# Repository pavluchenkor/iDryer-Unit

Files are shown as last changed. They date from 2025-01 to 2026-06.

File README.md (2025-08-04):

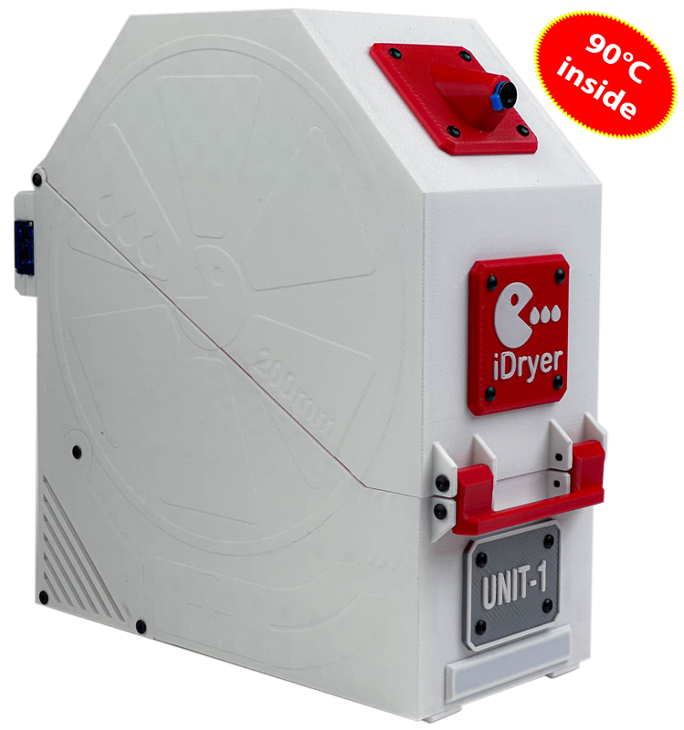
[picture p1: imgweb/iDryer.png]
iDryer Unit Master



    

# iDryer Unit - Filament Drying System for 3D Printers Based on Klipper

### Project Release

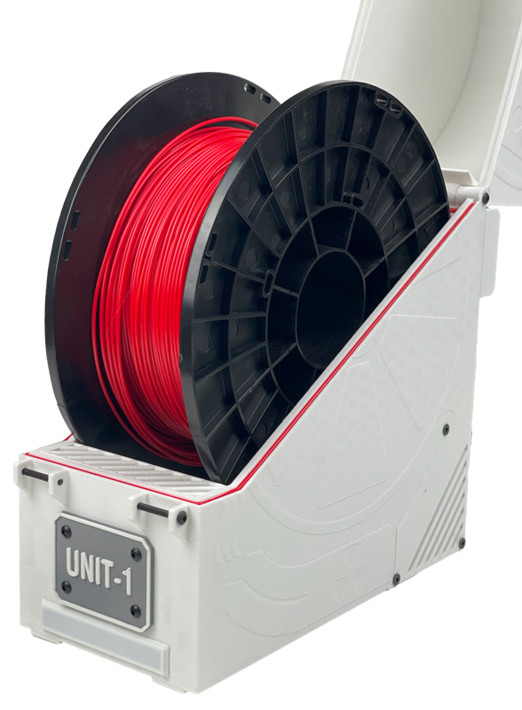
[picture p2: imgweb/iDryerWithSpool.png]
iDryer Unit Master


This project is a modular filament drying control system for 3D printers. It supports up to four drying units, each with individual temperature and humidity settings. The system allows setting temperatures up to 90°C and includes a storage mode that maintains minimal humidity to prevent filament reabsorption.

Additionally, iDryer Unit supports connection to a Telegram bot to receive notifications about drying status, process completion, and events like overheating. For visual indication, addressable LEDs can be used-an output on the MCU board allows connecting an LED strip to display various states (e.g., active drying mode, cycle completion, or errors). The system can leverage Klipper functionality to show temperature, humidity, remaining drying time, automatically log events, and integrate with macros. It also supports advanced user profiles and extended scenarios such as scheduled startup, critical event alerts, and lighting features like color changes between modes.

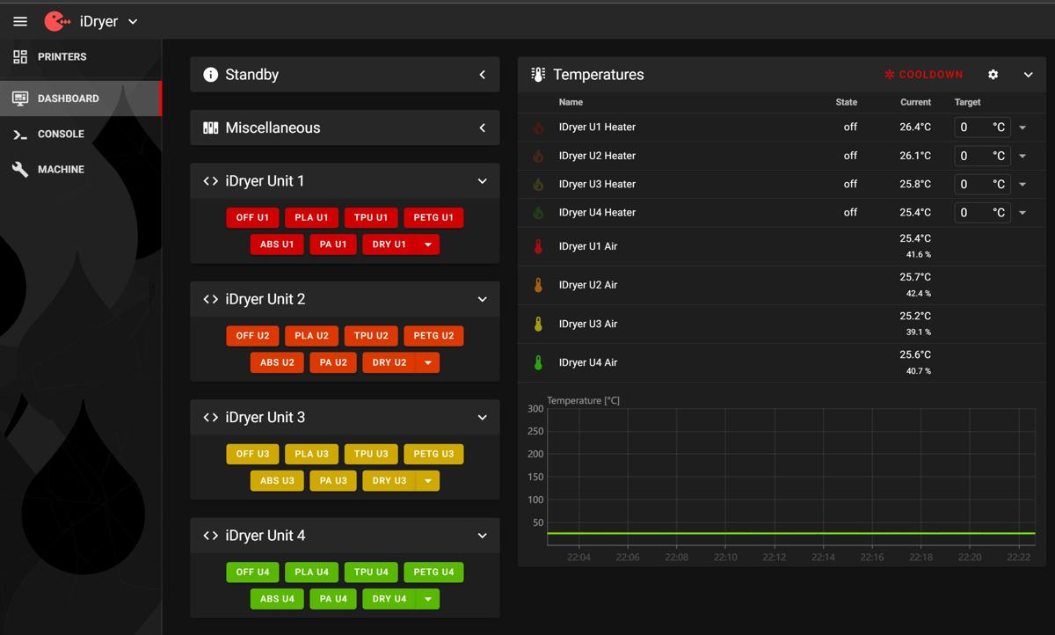
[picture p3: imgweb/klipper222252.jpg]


## Key Features

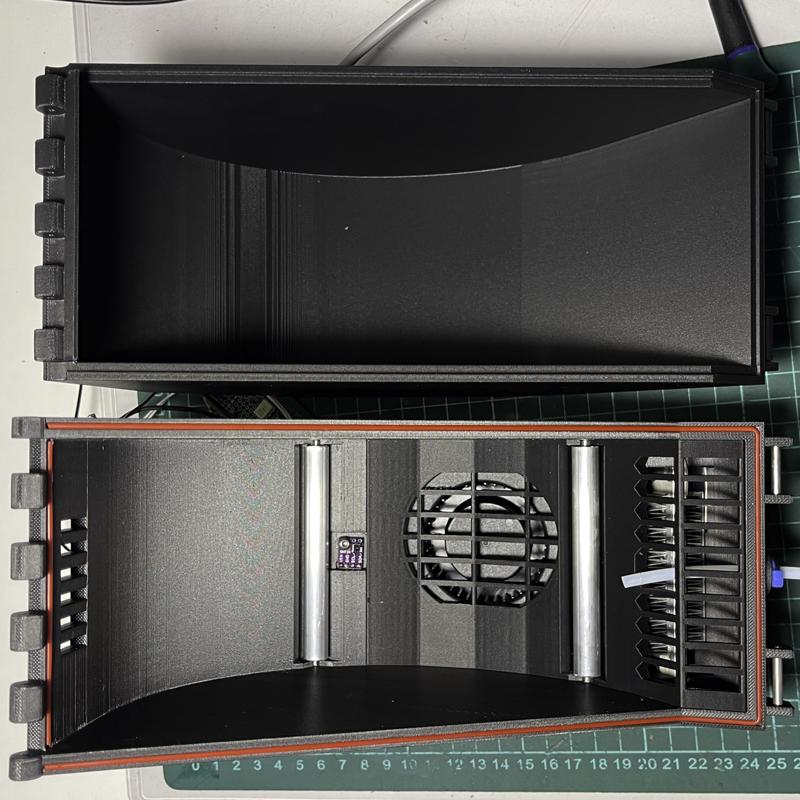
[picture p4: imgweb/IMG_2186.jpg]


* **Operating Modes: Drying and Storage.** Drying filament up to 90°C and maintaining ideal temperature and humidity for storage.

* **Modular Design:**

  * **iDryer Unit MCU** - main control unit with microcontroller.

  * **iDryer Unit EXT** - expansion modules without microcontrollers, connectable to the MCU unit. Up to three EXT units can be added.

* **Klipper Integration:** Display all drying parameters within Klipper interface.

* **Telegram Bot Notifications:** Receive real-time updates about status and process completion.

* **Visual Indication:** Addressable LEDs display current operating modes.

* **Printable Enclosure:** Available for one or two spools. Compatible with spools up to 85 mm wide and 200 mm in diameter. Can be printed using ABS or other suitable filament.

* **System Scalability:** Supports up to four drying units with individual settings. Each dryer can handle one or two spools simultaneously.

* **Add-on Module Support:** Additional dryers connect via patch cords using RJ45 connectors for reliable communication.

* **Centralized Architecture:** One dryer unit has an MCU and acts as the controller, while others are peripherals. iDryer can also be set up as a standalone Klipper instance or as a secondary MCU connected to the main printer board.

* **Safety:** Includes 130°C KSD9700 thermostat and Klipper safety mechanisms.

* **Drying Efficiency:** Features a humidity sensor and a servo-driven damper to manage chamber ventilation and achieve optimal drying results.
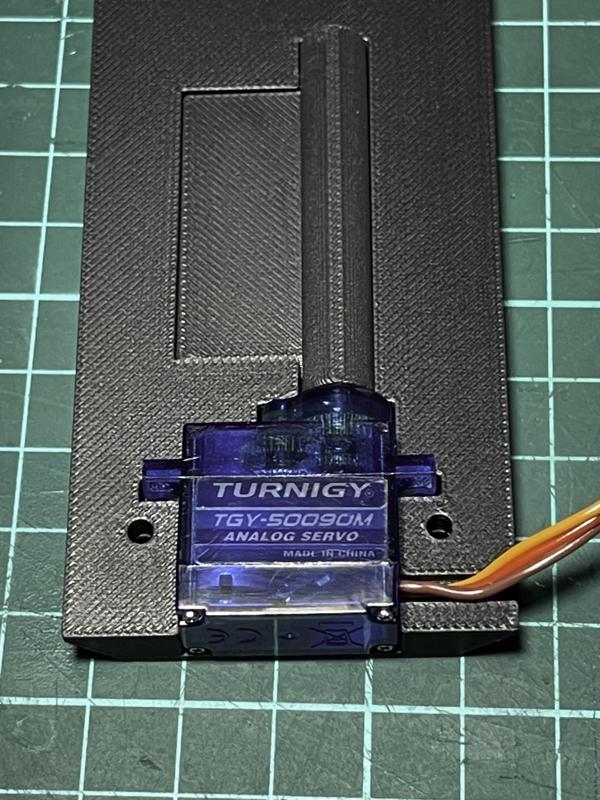
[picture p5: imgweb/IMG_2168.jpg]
  
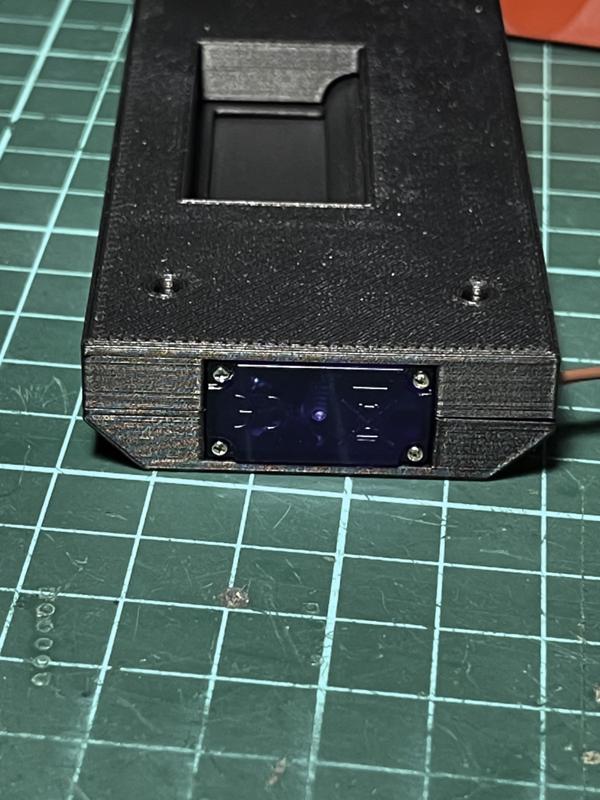
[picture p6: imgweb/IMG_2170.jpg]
  

## Benefits of Use

* **Improved Print Quality:** Dry filament ensures consistent extrusion and better print results.
* **Time Savings:** Simultaneous drying of multiple spools.
* **Efficiency:** Boosts productivity by reducing drying time.
* **Flexibility:** Expandable and customizable for specific needs.
* **Visualization:** LED feedback enables quick device status assessment.
* **Safety:** Both hardware and firmware safety measures ensure secure operation.

## Technical Details

* **iDryer Unit MCU:** Main controller block with microcontroller.
* **iDryer Unit EXT:** Expansion module without microcontroller.
* **MCU:** Manages the main dryer and coordinates additional modules. Default connection is U1; U2-U4 are optional. iDryer can function as a separate Klipper instance or as a second MCU within a single Klipper setup.
* **Thermostat KSD9700:** 130°C bimetallic thermostat for emergency protection.
* **Temperature Range:** Drying up to 90°C, suitable for most filament types.
* **Connection Interfaces:** RJ45 connectors simplify installation and ensure reliable connections.
* **LED Output:** Allows connecting addressable LED strips for visual feedback.

## Operating Modes

**1. Drying Mode (DRYING)**

* Set temperature and drying duration.
* Automatically switches to storage mode upon completion.

**2. Storage Mode (STORAGE)**

* Maintains target temperature and humidity.
* Activates heater and fan if thresholds are exceeded.

## Setup and Configuration

**Connection:** Link additional modules to the main dryer using RJ45 patch cords. U1 connects by default; U2-U4 can be added by including the appropriate config files.

## Requirements

* 3D printer with up-to-date Klipper firmware.
* iDryer board with MCU for the main dryer.
* KSD9700 thermostat (130°C) per dryer.
* RJ45 patch cords and connectors to link expansion modules.
* Extra iDryer Unit control boards depending on the number of dryers used.

---

## Feedback

If you have questions or suggestions for improvement, please open an issue in the repository or reach out directly.

Or join the Telegram group.

## Notes

* Ensure temperature and humidity sensors (e.g., SHT3X or alternatives) are connected correctly.
* PID tuning may be needed for optimal temperature control.
* Use macros to monitor temperature and humidity readings for precise drying conditions.
* This project is under active development.

***Warning: Using heating elements and temperature control involves fire risk and potential equipment damage. Always follow manufacturer guidelines and adhere to electrical safety precautions. Never leave operating devices unattended.***

### DIY Version from Scrap Materials

You can build a prototype of the iDryer Unit yourself on a minimal budget. This is a prototype and should be treated accordingly.

[EasyEDA Project](https://oshwlab.com/pavluchenko.r/2channel-dimmer-bread-board)

### Using a Printer Board

Another excellent option is to reuse an old printer board as an MCU, with solid-state relays to control 110-220V loads.






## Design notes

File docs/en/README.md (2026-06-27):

# iDryer Unit

iDryer Unit is a modular filament drying and storage system for 3D printers. Printable enclosure for 1 or 2 spools, up to four independent drying chambers in a single system.

Drying temperature — up to 90 °C in a standard enclosure, up to 110 °C with heat-resistant enclosure materials. Supported modes: Drying, Storage, and Profile.

iDryer Unit

## Who this project is for

iDryer Unit is a DIY project for those who want a reliable dryer with real control over the process, not a ready-made commercial device with a closed-source interior.

All components are standard and readily available: fan, PTC heater, temperature and humidity sensor, servo, Thermal Protector. Any of them can be replaced without searching for proprietary spare parts. Unlike most mass-produced dryers, there is nothing here that cannot be repaired or improved.

The enclosure is printed on any 3D printer. Schematics, firmware, and documentation are open.

iDryer Unit with spool

---

## Two modes of operation

Choose a scenario before starting assembly — it determines the firmware and control method.

### Klipper

Klipper

The Unit controller connects to the printer host and operates as `[mcu]` or `[second_mcu]` in Klipper. Control is via the Fluidd / Mainsail interface, G-code macros, and integration with the main printer config.

Additional Klipper features are available: notifications via Telegram bot (drying status, cycle completion, overheating), addressable LED strip for visual mode indication, automatic event logging.

Suitable if:

- you already have Klipper running;
- you want to control the dryer directly from the printer interface;
- you need deep integration with macros and scheduling.

→ [Klipper Firmware](controller/firmware.md)

### Standalone

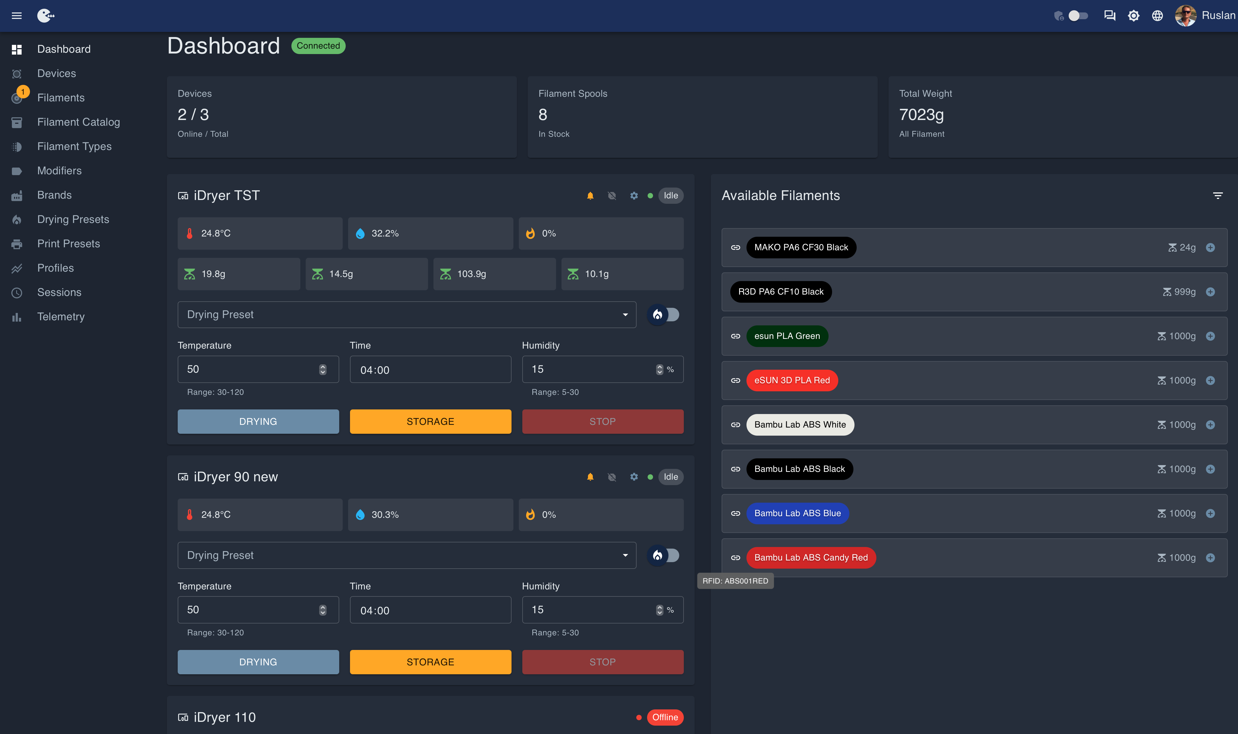
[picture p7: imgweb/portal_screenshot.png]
iDryer Portal


The controller operates independently: its own firmware, control via the cloud portal [portal.idryer.org](https://portal.idryer.org/) and mobile app. Optionally — local control via OLED display and encoder. Scales (filament remainder control by weight) and RFID (automatic spool identification) are supported.

Suitable if:

- you want a dryer separate from the printer;
- you need remote control via mobile app or portal;
- you use multiple dryers with a single control point.

→ [Standalone: about firmware](../../../iDryerRP2040/README.md)

---

## Specifications

| Parameter | Value |
|---|---|
| Drying temperature | up to 90 °C (up to 110 °C with heat-resistant enclosure) |
| Modes | Drying, Storage, Profile (Standalone) |
| Number of chambers | 1–4 (MCU + up to 3 × EXT) |
| Module connection | RJ45 patch cables |
| Thermal Protector | KSD9700 (130 °C) |
| Current protection | 2 A fuse |
| Heating element | PTC, full electrical isolation |
| Spools | 1 or 2 per chamber; width up to 85 mm, diameter up to 200 mm |
| Enclosure options | Single-spool and dual-spool |
| Enclosure material | Printable, ABS / ABS-CF / PC / HTPLA |
| Humidity sensor | SHT3X or any supported by firmware |
| LED indication | Addressable LED strip output on MCU board |

---

## Operating modes

**Drying** — set temperature and duration. When the cycle ends, the system automatically switches to Storage mode.

**Storage** — maintains the set temperature and minimum humidity level. The heater and fan activate when the set parameters are exceeded.

**Profile** — custom scenarios with configurable parameters and transitions between modes. Available in Standalone firmware.

---

## Humidity control

Each chamber has a servo-controlled damper. The servo opens the damper on a schedule to vent moisture-saturated air and closes it to retain heat. The SHT3X sensor continuously monitors temperature and humidity inside the chamber — the firmware adjusts the damper and heater operation based on this data.

iDryer Unit damper
Damper mechanism

---

## System architecture

One **iDryer Unit MCU** board controls the system. Up to three **iDryer Unit EXT** boards (without their own microcontroller) connect directly via RJ45.

```
              ┌— RJ45 — [EXT U2]
[MCU] ————————┼— RJ45 — [EXT U3]
              └— RJ45 — [EXT U4]
```

Each unit is an independent drying chamber with its own sensor, heater, fan, and damper servo.

---

## Built-in safety

- **KSD9700** — Thermal Protector at 130 °C: physically opens the heater circuit on overheating.
- **2 A fuse** — protection against fault currents.
- **PTC heater** — the heater body is not live.
- **Software protection** — Klipper (or Standalone firmware) monitors temperature, sensor presence, and shuts off heating on error.

!!! danger "Working with mains voltage"
    The device contains components operating at 110–230 V. Disconnect power before any electrical work. See the [Safety](unit/safety.md) section for details.

---

## Getting started

1. **Print the enclosure** → [CAD: models for printing](unit/cad.md)
2. **Prepare components** → [Before assembly](unit/before.md)
3. **Assemble the device** → [Assembly](unit/assembly.md)
4. **Install firmware**:
   - Klipper → [Klipper Firmware](controller/firmware.md)
   - Standalone → [Standalone installation](../../../iDryerRP2040/docs/manual/firmware_install.md)
5. **Configure the system** → [User guide](controller/user-guide.md)

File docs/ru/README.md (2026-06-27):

# iDryer Unit

iDryer Unit — модульная система сушки и хранения филамента для 3D-принтеров. Печатаемый корпус на 1 или 2 катушки, до четырёх независимых сушильных камер в одной системе.

Температура сушки — до 90 °C в стандартном корпусе, до 110 °C при использовании теплостойких материалов корпуса. Поддерживаемые режимы — сушка (Drying), хранение (Storage) и профили (Profile).

iDryer Unit

## Для кого этот проект

iDryer Unit — DIY-проект для тех, кто хочет надёжную сушилку с реальным контролем над процессом, а не готовое коммерческое устройство с закрытой начинкой.

Все компоненты — стандартные и доступные: вентилятор, PTC-нагреватель, датчик температуры и влажности, сервопривод, Thermal Protector. Любой из них можно заменить без поиска фирменных запчастей. В отличие от большинства серийных сушилок, здесь нет ничего, что нельзя починить или улучшить.

Корпус печатается на любом 3D-принтере. Схемы, прошивки и документация открыты.

iDryer Unit с катушкой

---

## Два варианта работы

Выберите сценарий до начала сборки — от него зависит прошивка и способ управления.

### Klipper

Klipper

Контроллер Unit подключается к хосту принтера и работает как `[mcu]` или `[second_mcu]` в Klipper. Управление — через интерфейс Fluidd / Mainsail, макросы G-кода, интеграция с основным конфигом принтера.

Доступны дополнительные функции Klipper: уведомления через Telegram-бот (статус сушки, завершение цикла, перегрев), адресная светодиодная лента для визуальной индикации режимов, автологирование событий.

Подходит, если:

- у вас уже работает Klipper;
- хотите управлять сушилкой прямо из интерфейса принтера;
- нужна глубокая интеграция с макросами и расписанием.

→ [Прошивка Klipper](controller/firmware.md)

### Standalone

iDryer Portal

Контроллер работает самостоятельно: своя прошивка, управление через облачный портал [portal.idryer.org](https://portal.idryer.org/) и мобильное приложение. Опционально — локальное управление через OLED-экран и энкодер. Поддерживаются весы (контроль остатка филамента по весу) и RFID (автоматическое определение катушки).

Подходит, если:

- хотите сушилку отдельно от принтера;
- нужен удалённый контроль через мобильное приложение или портал;
- используете несколько сушилок с одной точкой управления.

→ [Standalone: о прошивке](../../../iDryerRP2040/README.md)

---

## Характеристики

| Параметр | Значение |
|---|---|
| Температура сушки | до 90 °C (до 110 °C с теплостойким корпусом) |
| Режимы | Drying, Storage, Profile (Standalone) |
| Количество камер | 1–4 (MCU + до 3 × EXT) |
| Подключение модулей | RJ45 патчкорды |
| Thermal Protector | KSD9700 (130 °C) |
| Защита по току | предохранитель 2 А |
| Нагревательный элемент | PTC, полная электрическая изоляция |
| Катушки | 1 или 2 на камеру; ширина до 85 мм, диаметр до 200 мм |
| Варианты корпуса | На 1 катушку и на 2 катушки |
| Материал корпуса | Печатаемый, ABS / ABS-CF / PC / HTPLA |
| Датчик влажности | SHT3X или любой, поддерживаемый прошивкой |
| Светодиодная индикация | выход для адресной LED-ленты на плате MCU |

---

## Режимы работы

**Drying (сушка)** — задайте температуру и время. По истечении цикла система автоматически переходит в режим Storage.

**Storage (хранение)** — поддерживает заданную температуру и минимальный уровень влажности. Нагреватель и вентилятор включаются при превышении заданных параметров.

**Profile (профиль)** — пользовательские сценарии с настраиваемыми параметрами и переходами между режимами. Доступен в Standalone-прошивке.

---

## Управление влажностью

Каждая камера оснащена управляемой заслонкой. Сервопривод открывает заслонку по расписанию для вывода насыщенного влагой воздуха и закрывает её для удержания тепла. Датчик SHT3X непрерывно контролирует температуру и влажность внутри камеры — прошивка корректирует режим работы заслонки и нагревателя на основе этих данных.

Заслонка iDryer Unit
Механизм заслонки

---

## Архитектура системы

Один блок **iDryer Unit MCU** управляет системой. К нему напрямую через RJ45 подключаются до трёх блоков **iDryer Unit EXT** без собственного микроконтроллера.

```
              ┌— RJ45 — [EXT U2]
[MCU] ————————┼— RJ45 — [EXT U3]
              └— RJ45 — [EXT U4]
```

Каждый блок — независимая сушильная камера со своими датчиком, нагревателем, вентилятором и сервоприводом заслонки.

---

## Встроенная безопасность

- **KSD9700** — Thermal Protector на 130 °C: физически размыкает цепь нагревателя при перегреве.
- **Предохранитель 2 А** — защита при аварийных токах.
- **PTC-нагреватель** — корпус нагревателя не находится под напряжением.
- **Программная защита** — Klipper (или Standalone-прошивка) контролирует температуру, наличие датчиков и отключает нагрев при ошибке.

!!! danger "Работа с сетевым напряжением"
    Устройство содержит компоненты под напряжением 110–230 В. Перед любыми работами с электрикой отключайте питание. Подробнее — в разделе [Безопасность](unit/safety.md).

---

## С чего начать

1. **Распечатайте корпус** → [CAD: модели для печати](unit/cad.md)
2. **Подготовьте комплектующие** → [Перед сборкой](unit/before.md)
3. **Соберите устройство** → [Сборка](unit/assembly.md)
4. **Установите прошивку**:
   - Klipper → [Прошивка Klipper](controller/firmware.md)
   - Standalone → [Установка Standalone](../../../iDryerRP2040/docs/manual/firmware_install.md)
5. **Настройте систему** → [Руководство пользователя](controller/user-guide.md)

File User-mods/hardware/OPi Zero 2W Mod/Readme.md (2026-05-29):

# [OPi_Zero_2W_Mod]

>[!NOTE]
>На момент разработки модификации возможность автономной работы iDryer Unit отсутствовала - модификация **может быть актуальна** для плат старше 2025 года.

Модификация для сушилки iDryer, позволяющая использовать её независимо от принтера за счёт увеличенного отсека электроники и установки OPi Zero 2w. Для максимальной компактности в части кабель-менеджемента крайне рекомендуется делать совместно с [UART mod](https://github.com/DieselFork/iDryer-Unit/tree/main/User-mods/hardware/UART%20mod).

>[!WARNING]
>Работоспособность UART мода обеспечивается использованием одного из разъёмов расширения - одновременно можно будет подключить только 2 EXT платы.

## Рендеры

### Вид спереди

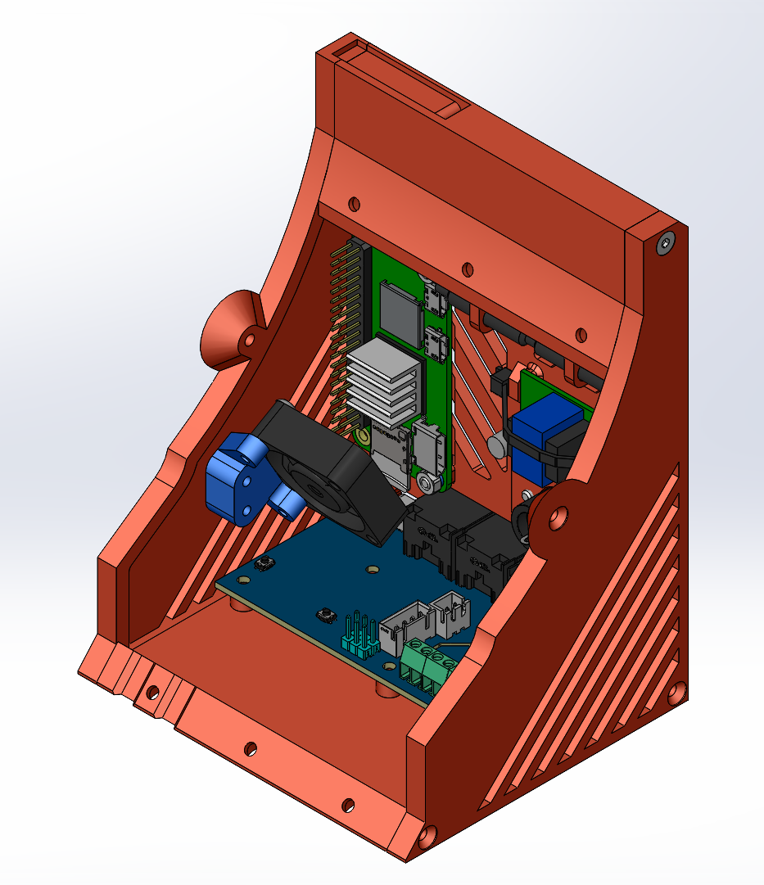
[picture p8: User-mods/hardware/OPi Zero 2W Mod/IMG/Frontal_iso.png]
Фронтальная_изометрическая_проекция


### Вид сзади

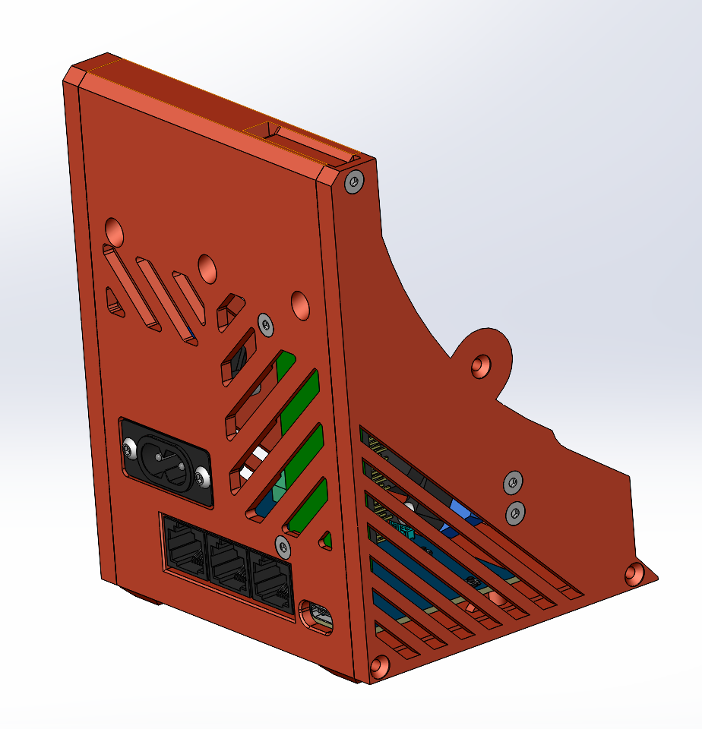
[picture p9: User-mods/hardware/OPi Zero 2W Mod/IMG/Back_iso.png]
Вид_сзади


## BOM

### Докупаемые детали

1. [Orange Pi Zero 2 W](https://aliexpress.ru/item/1005007543231333.html), желательно брать версию с 2 Гб памяти, с расчётом на дополнительные модификации.
2. [Блок питания 5В, 2А](https://aliexpress.ru/item/1005001970797548.html?sku_id=12000018270798953), не менее. Если сделать не очень качественно серво-заслонку (когда шторка цепляется за корпус), то могут быть просадки по питанию.
3. [Вентилятор 3010, 5В](https://aliexpress.ru/item/4000256787938.html?sku_id=12000032631942721), охлаждение процессора OPi Zero 2w. OPi Zero 2w - сами по себе горячие, в простое (даже на столе без работы сушилки) температура может подниматься до 50 градусов.
4. [Радиатор 14х14х10 мм](https://aliexpress.ru/item/32956250962.html?sku_id=12000030307252205) для процессора OPi Zero 2w. Также для крепления радиатора к процессору понадобится термопаста.
5. Кабель USB Type-C, потребуется часть с type-C разъёмом для подключения OPi Zero 2w к блоку питания. Как вариант, можно кабель не покупать и подключить 5В и GND от блока питания на гребёнку, но в данном случае придётся объединить 5В от блока питания с 5В вентилятора или UART, т.к. таких пинов на гребёнке всего лишь два.
6. Кабельный хомут 2,5х150, для крепления блока питания.
7. Винты с потайной головкой M3x10 DIN 7991 - 4 шт, для крепления OPi Zero 2w и кронштейна вентилятора. Можно заменить на M3x12 DIN 7991 для унификации.
8. Винты с потайной головкой M3x12 DIN 7991 - 2 шт, для верхней части отсека электроники.
9. Винты с полусферической головкой M3x14 ISO 225 - 2 шт, для крепления вентилятора 3010.

>[!WARNING]
>При покупке не ошибитесь с длиной винтов, т.к. нормативная документация на винты с потайной и полусферической головкой разная. Длина в обозначение винта согласно DIN 7991 указывается с учётом высоты головки, а согласно ISO 225 в обозначении указывается только длина резьбовой части.

10. Гайки M3 DIN 934 - 2 шт, для крепления OPi Zero 2w.

### Печатаемые детали

1. Центральная часть EE_BackCover - 1 шт.
2. Боковая стенка EE_Side_L, левая - 1 шт.
3. Боковая стенка EE_Side_R, правая - 1 шт.

>[!WARNING]
>Обратите внимание на название моделей из пунктов 1-3 - есть варианты для старой (обозначены как Old_PCB) и актуальной MCU платы.
>На июль 2025 года **актуальные MCU платы имеют габариты 90х50 мм** и крепятся внутри отсека с помощью трёх винтов М3х6, **старые - имели габариты 100х49 мм** и зажимались в прорезях боковых стенок при сборке.

4. Кронштейн вентилятора Fan_Bracket - 1 шт.
5. Пластиковые шайбы Spacer_5-3,2-1 - 2 шт, для изоляции гайек от платы OPi Zero 2w. Фактически диэлектрические шайбы под резьбу М3 и высотой 1 мм.

## Сборка

Фотографии даны для облегчения понимания сборки. Стоит учесть, что на фотографиях одна из первых модификаций MCU платы и первый вариант корпуса, а также крепёж OPi Zero 2w будет отличаться от BOM и моделей.

### Подключение UART и вентилятора

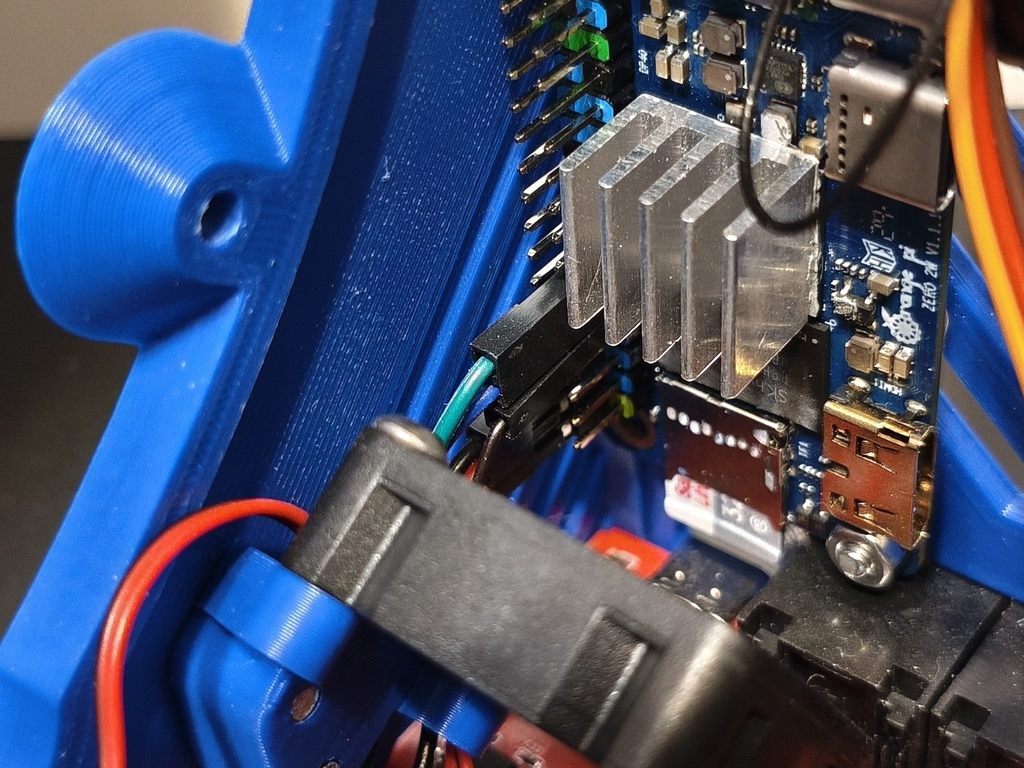
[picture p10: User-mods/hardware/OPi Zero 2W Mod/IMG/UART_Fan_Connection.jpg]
ЮАРТ_обдув


### Подключение блока питания

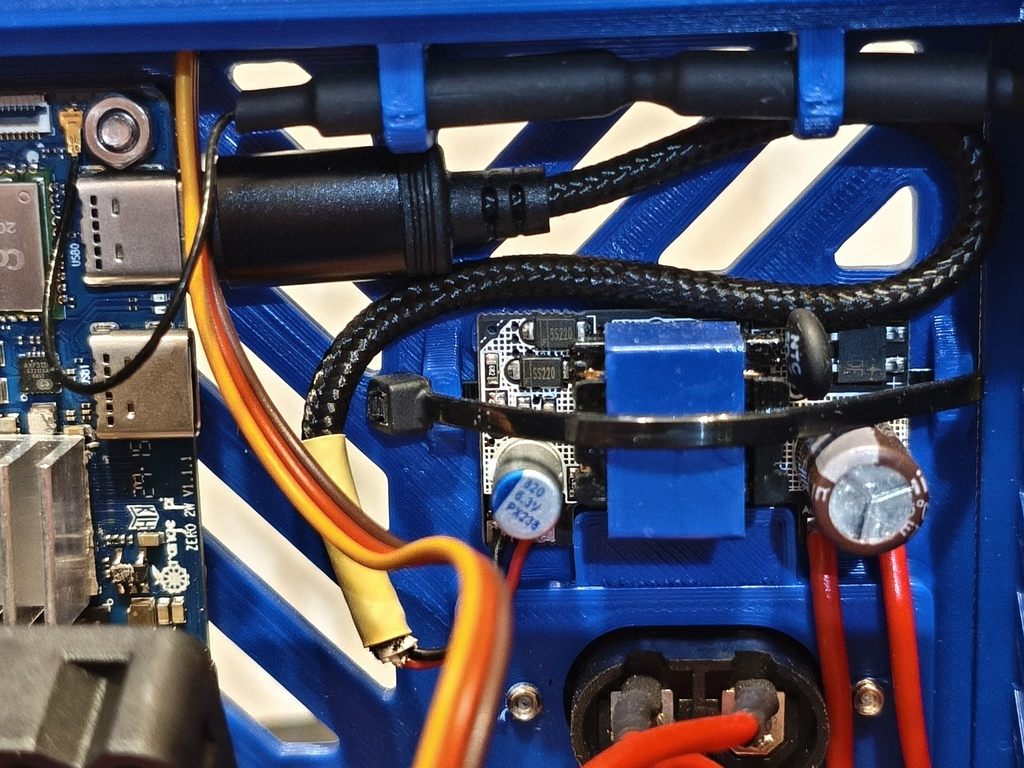
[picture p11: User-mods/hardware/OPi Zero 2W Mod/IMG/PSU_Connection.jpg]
Подключение_БП


### Подключение сервопривода

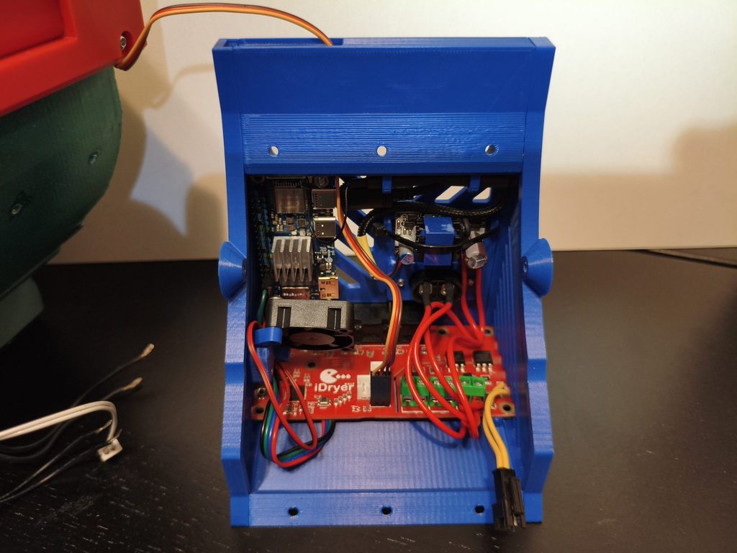
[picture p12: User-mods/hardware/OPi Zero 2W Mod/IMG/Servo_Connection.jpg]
Подключение_сервопривода


### Электроника в сборе

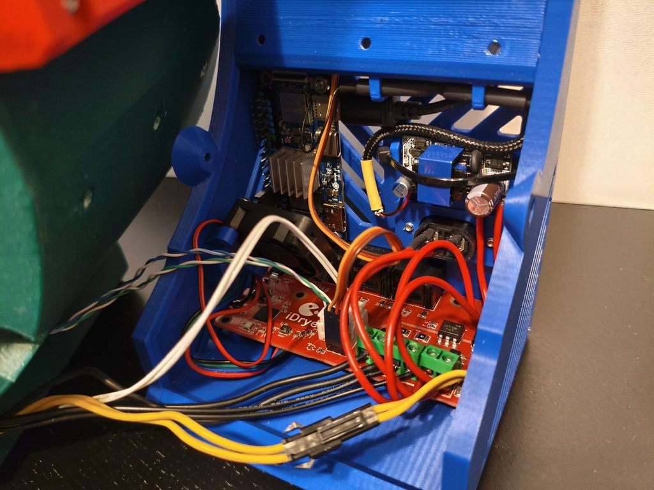
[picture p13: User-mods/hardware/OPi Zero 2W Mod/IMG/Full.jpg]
Вся_электроника


### Установленный отсек электроники

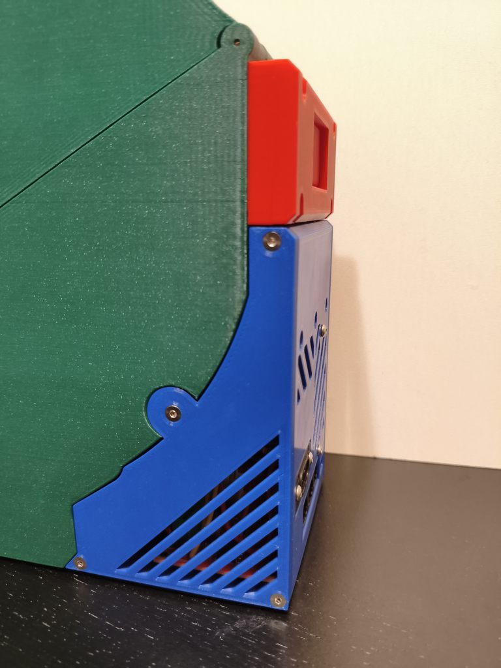
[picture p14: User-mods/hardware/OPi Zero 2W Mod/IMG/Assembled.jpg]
Установленный_отсек_электроники


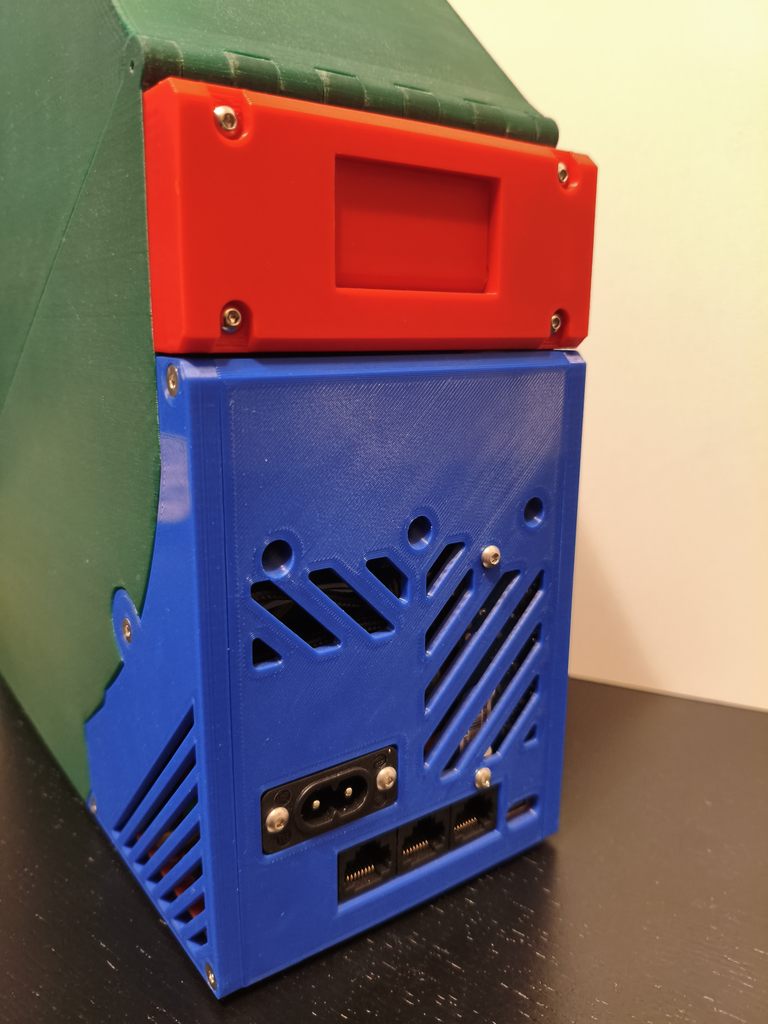
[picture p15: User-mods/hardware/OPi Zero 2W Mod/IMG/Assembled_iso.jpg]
Установленный_отсек_электроники_изометрия


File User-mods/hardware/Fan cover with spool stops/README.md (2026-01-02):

Fan cover with spool stops

This mod is useful when using the iDryer Unit in the dual-spool configuration. The tall stops prevent the spool edge from rolling between the rollers and getting stuck there.

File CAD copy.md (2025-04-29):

# Модели для печати
!!! success "Файлы для печати"

    **[База MCU](CAD/v3/UNIT%20MCU%20Base%20screw%20mounting.stl)**

    **[База EXT](CAD/v3/UNIT%20EXT%20Base%20screw%20mounting.stl)**

    **[Верхняя крышка](CAD/v3/UNIT%20Top%20Cover%20screw%20mounting.stl)**

    **[Задняя крышка отсека электроники EXT](CAD/v3/UNIT%20EXT%20Back%20Cover.stl)**

    **[Задняя крышка отсека электроники MCU](CAD/v3/UNIT%20MCU%20Back%20Cover.stl)**
    
    **[Левая крышка отсека электроники](CAD/v3/UNIT%20Left%20Cover.stl	)**

    **[Правая крышка отсека электроники](CAD/v3/UNIT%20Right%20Cover.stl	)**

    **[Ручка-защелка](CAD/v3/UNIT%20Latch%20Handle.stl	)**

    **[Защелка](CAD/v3/UNIT%20Latch.stl	)**

    **[Выход филамента](CAD/v3/UNIT%20Filament%20Outlet.stl)**

    **[Пол](CAD/v3/UNIT%20Floor.stl)**

    **[Фиксатор датчика](CAD/v3/UNIT%20Floor%20Sensor%20Retainer.stl)**

    **[Рассеиватель  MCU](CAD/v3/UNIT%20MCU%20Light%20diffuser.stl)**

    **[Разделитль 1 MCU](CAD/v3/UNIT%20MCU%20Light%20separator.stl)**
    
    **[Разделитль 2 MCU](CAD/v3/UNIT%20MCU%20Light%20separator%202.stl)**
    
    **[Разделитль 3 MCU](CAD/v3/UNIT%20MCU%20Light%20separator%203.stl)**
    
    **[Разделитль 4 MCU](CAD/v3/UNIT%20MCU%20Light%20separator%204.stl)**

    **[Заслонка](CAD/v3/UNIT%20Servo%20damper.stl)**
    
    **[Корпус заслонки низ](CAD/v3/UNIT%20Servo%20damper%20Lower%20Housing.stl)**
    
    **[Корпус заслонки верх](CAD/v3/UNIT%20Servo%20damper%20Upper%20Housing.stl)**

    **[Логотип](CAD/v3/UNIT%20Logo%20Plate.stl	)**
    
    **[Табличка 1](CAD/v3/UNIT%20Name%20Plate%201.stl	)**
    
    **[Табличка 2](CAD/v3/UNIT%20Name%20Plate%202.stl	)**
    
    **[Табличка 3](CAD/v3/UNIT%20Name%20Plate%203.stl	)**
    
    **[Табличка 4](CAD/v3/UNIT%20Name%20Plate%204.stl	)**
    
    **[Опора](CAD/v3/UNIT%20Foot.stl)**

    **[Заглушка](CAD/v3/UNIT%20Plug%201.stl)**

    **[Заглушка](CAD/v3/UNIT%20Plug%202.stl)**

    **Duo**

    **[Задняя крышка отсека электроники Duo](CAD/v3/UNIT%20MCU%20duo%20Back%20Cover.stl)**

    **[База MCU Duo](CAD/v3/UNIT%20MCU%20duo%20Base%20screw%20mounting.stl)**

    **[Лоток для силикагеля Duo](CAD/v3/UNIT%20duo%20silica%20tray.stl)**

    **[Верхняя крышка Duo](CAD/v3/UNIT%20duo%20Top%20Cover%20screw%20mounting.stl)**

#### Параметры печати корпуса:

  - материал ABS, ABS-CF, ABS-GF, PP

  - ширина линии 0.6 - 0.8 (необходимо проверить чтобы при печати сформировались четкие камеры)

  - количество периметров 1
  
  - заполнение 10-15% 

  - шаблон заполнения прямолинейный

  - радиус закрытия пробелов(зазоров) 0.02

  Все детали корпуса печатаются без поддержек

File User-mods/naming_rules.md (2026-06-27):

# NAMING_RULES - file and assembly naming system for projects

This document defines a unified standard for naming **parts, assemblies, and components** for all device families (e.g., **UNIT**, **IHEATER**, **IDRYER**, etc.). Following these rules ensures clarity, consistency, and scalability of names in CAD/PLM, on the website, in BOMs, and when sharing files.

---

## General principles
- The first element in the name is always the **device name** (DEVICE): `UNIT`, `IHEATER`, `IDRYER`, …
- All names in the project must follow the same naming convention.
- The structure should work uniformly across different devices.

---

## Name format

```
<DEVICE>_[<VARIANT>_] <MODULE> _ <PART> [ _ <SUFFIX1> [ _ <SUFFIX2> ... ] ]
```

**Where:**
- `<DEVICE>` - the device or product family name:
  - `UNIT` - Unit device
  - `IHEATER` - iHeater device
  - `IDRYER` - iDryer device
- `<VARIANT>` - **device variant** (optional):
  - `MCU` - specific to Unit MCU version
  - `EXT` - specific to Unit EXT version
  - `DUO`, `PRO`, etc. - for future variants
  - absence of `<VARIANT>` = part is **shared** across all variants
- `<MODULE>` - **major assembly/block** of the device:
  - `BASE`, `COVER`, `ELEC`, `SCREEN`, `SPOOL`, `ROLLER`, `DAMPER`, `LABEL`, `FLOOR`, `INLET`, `OUTLET`, …
- `<PART>` - specific part/function: `plate`, `frame`, `mount`, `holder`, `diffuser`, …
- `<SUFFIX*>` - optional clarifiers: side, size, version, revision (`left`, `right`, `v2`, `revA`, …).

---

## Examples

**Shared parts (for all device variants):**
```
UNIT_COVER_MAIN
UNIT_ROLLER_SMALL
IHEATER_BASE_PLATE
```

**MCU-specific parts:**
```
UNIT_MCU_SCREEN_FRAME
UNIT_MCU_ELEC_MOUNT
```

**EXT-specific parts:**
```
UNIT_EXT_ELEC_BOX
UNIT_EXT_SCREEN_DIFFUSER
```

**For other projects:**
```
IDRYER_BASE_FLOOR
IDRYER_DUO_COVER_TOP
```

---

## 3) Usage recommendations
- **Shared parts** must always be named without variant (`UNIT_`, `IHEATER_`, …).
- **Variant-specific parts** must be named with the variant (`UNIT_MCU_`, `UNIT_EXT_`).
- When new devices appear (e.g., iDryer Duo), apply the same format (`IDRYER_DUO_…`).
- Document all new names in `NAMING_RULES.md` so the team and users understand the system.

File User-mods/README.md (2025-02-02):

# How to Add Your Mod to This Repository

This guide is for users who want to add their own mods to this repository. Please follow the instructions below step by step to ensure your mod is correctly structured and easy to understand for others.

**Important: Original files are provided under the CC BY-NC-SA license. Any modifications or derivatives must be shared in this repository in accordance with the license terms and the repository submission guidelines. Commercial use is strictly prohibited.**

---
## 1. Fork the Repository (Required)
Before making changes, you must fork this repository to your own GitHub account:

Open the repository in GitHub:
https://github.com/pavluchenkor/iDryer-Unit
Click the "Fork" button in the top-right corner.
Choose your GitHub account as the destination.
Wait for GitHub to create a fork (this is your personal copy of the repository).

## 2. Clone Your Fork
After forking the repository, clone your own fork, not the original repository:

Option 1: Using Git (Recommended)
```
git clone https://github.com/YOUR-USERNAME/iDryer-Unit.git
cd iDryer-Unit
```
(Replace YOUR-USERNAME with your GitHub username.)

### Option 1: Using Git (Recommended)

1. Open your terminal or command prompt.
2. Clone the repository by running the following command:
   ```bash
   git clone https://github.com/pavluchenkor/iDryer-Unit.git

### Option 2: Download as a ZIP File

1. Click the green "Code" button at the top of the repository page.
2. Select "Download ZIP".
3. Extract the ZIP file to your computer.

## 3. Add Your Mod to the Correct Folder

Based on the type of mod you're creating, it should go into one of the following main directories:

#### Software Mods:

- If your mod involves configuration files, scripts, or code, it should be added to the software/ folder.

#### Hardware Mods:

- If your mod involves CAD models, mechanical components, or hardware designs, it should be added to the hardware/ folder.

### Examples:

#### For a Software Mod:
If your mod is called "CoolMod" and involves configuration or scripts, your folder structure should look like this:

```
├── hardware/
├── software/
│   ├── CoolMod/
│   │   ├── README.md
│   │   ├── scripts/
│   │   ├── config/
├── readme.md

```

#### For a Hardware Mod:
If your mod is called "CoolMod" and involves CAD models or mechanical components, your folder structure should look like this:
```
├── hardware/
│   ├── CoolMod/
│   │   ├── README.md
│   │   ├── models/
│   │   ├── assembly/
│   │   ├── diagrams/
├── software/
├── readme.md

```
## 4. Organize Your Mod Files

In your mod folder, create a clear and logical structure for your files. At a minimum, your mod folder should include the following:

### For Software Mods:

- README.md: A markdown file describing your mod (see template below).
- scripts/: A folder for scripts or additional functionality.
- config/: A folder for configuration files (if applicable).

### For Hardware Mods:

- README.md: A markdown file describing your mod (see template below).
- models/: A folder for CAD models or 3D files (e.g., .stl, .step).
- assembly/: A folder for assembly instructions or exploded views.
- diagrams/: A folder for electrical or mechanical diagrams.

## 5. Write a README.md for Your Mod

Every mod must include a README.md file inside its folder. This file should provide clear and detailed information about your mod. Use the following template to guide you:

### Template for README.md

#### [Mod Name]

##### Summary
A brief overview of your mod. Explain its purpose and what problem it solves.

#### Example:
"CoolMod is a software configuration mod for enhancing filament drying with custom profiles."

---

#### Features
- List the key features of your mod.
- Example:
- Supports multiple drying profiles.
- Offers advanced temperature and humidity control.

---

#### How to Use
Step-by-step instructions on how to use your mod. Include:
1. Installation instructions.
2. Integration steps (e.g., how to include it in the main repository).
3. Dependencies or requirements.

#### Example:
1. Copy the `CoolMod` folder into the `klipper/` directory.
2. Include the configuration in Klipper by adding:

   ```ini
   [include CoolMod/config/coolmod.cfg]
   ```

### Full Description

Provide detailed information about your mod, including:

- Screenshots or diagrams.
- Code snippets or configuration examples.
- Supported hardware/software versions.
- Specific use cases.

### Example:
Screenshots:
Code Snippet:

```
[gcode_macro COOL_MOD_START]
gcode:
    M117 Starting CoolMod...
```

### Notes
- Known limitations or compatibility issues.
- Suggestions for future updates or improvements.

### Author

Add your name or GitHub handle here (optional).

## 6. Submit Your Mod

### Option 1: Using Git

1. Add your changes to the repository:

```bash
git add .
git commit -m "Added CoolMod"
git push
```

2. Create a pull request on GitHub to merge your changes into the main repository.

### Option 2: Upload Files on GitHub

1. Open the repository on GitHub.
2. Navigate to the folder where you want to add your mod (hardware/ or software/).
3. Click "Add file" > "Upload files".
4. Select your mod folder and upload it.
5. Create a pull request to merge your changes.

## Important Notes

- Do not modify existing files or folders in the repository.
- Ensure your folder structure is clear and logical.
- Test your mod thoroughly before submitting it.
- Write a comprehensive and user-friendly README.md.

By following these guidelines, your mod will be easy to integrate and understand. If you have any questions, feel free to contact.

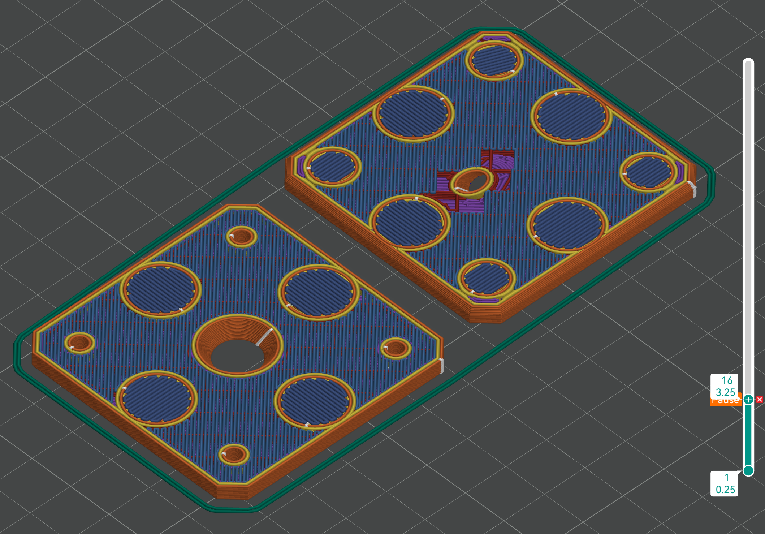
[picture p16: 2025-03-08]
User-mods/hardware/Flip Filament Out Mod/Img/Pause-on-layer.png

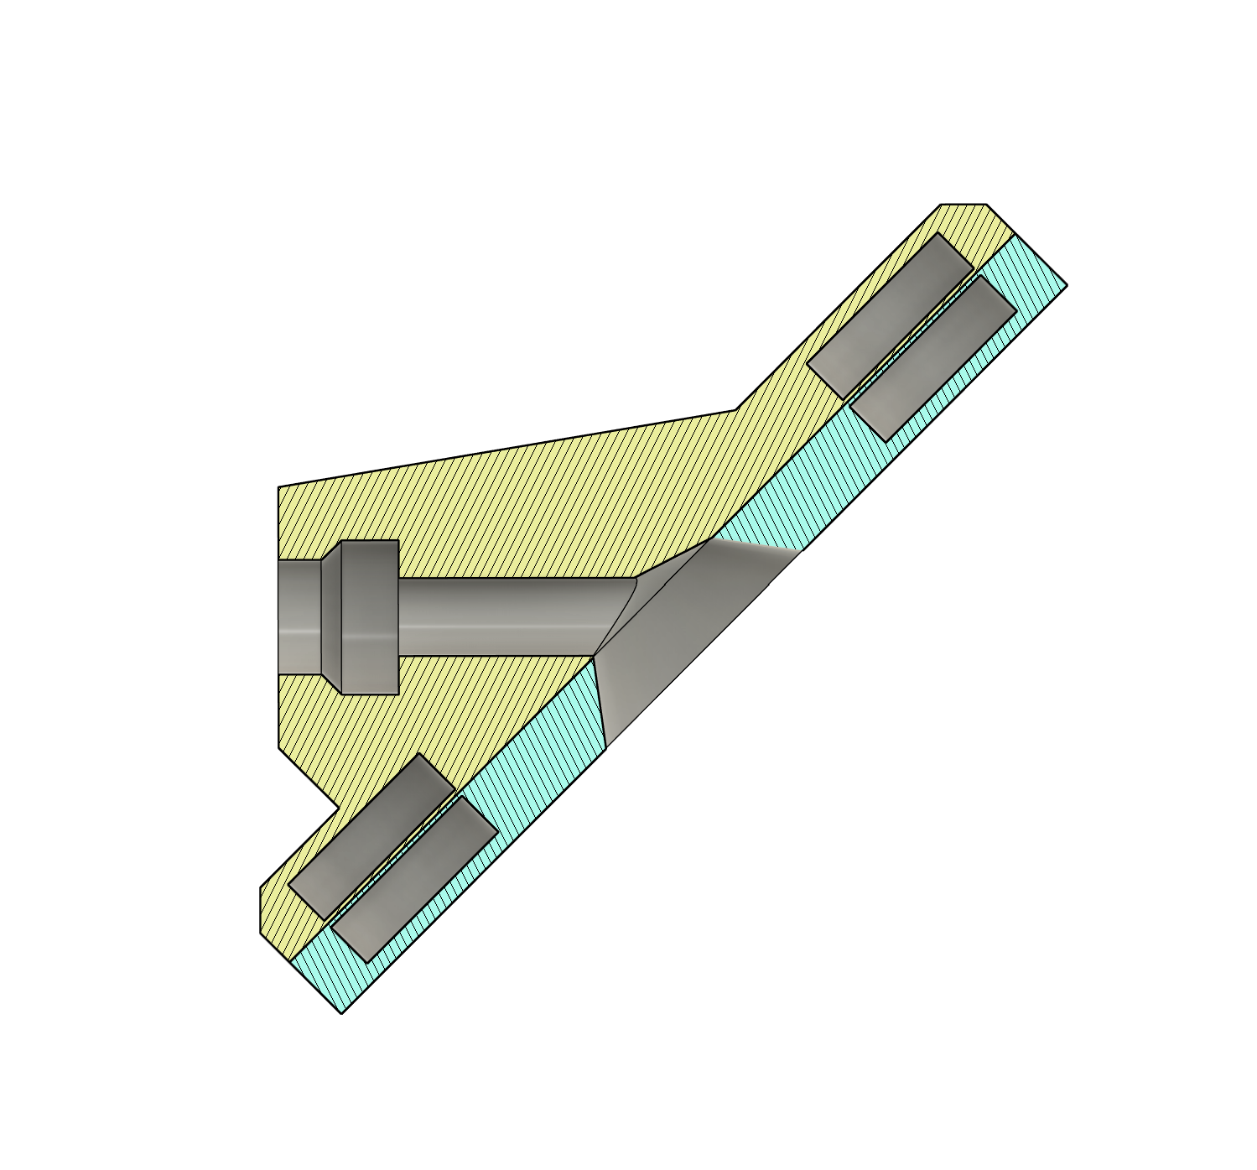
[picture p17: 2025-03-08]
User-mods/hardware/Flip Filament Out Mod/Img/cut-view.png

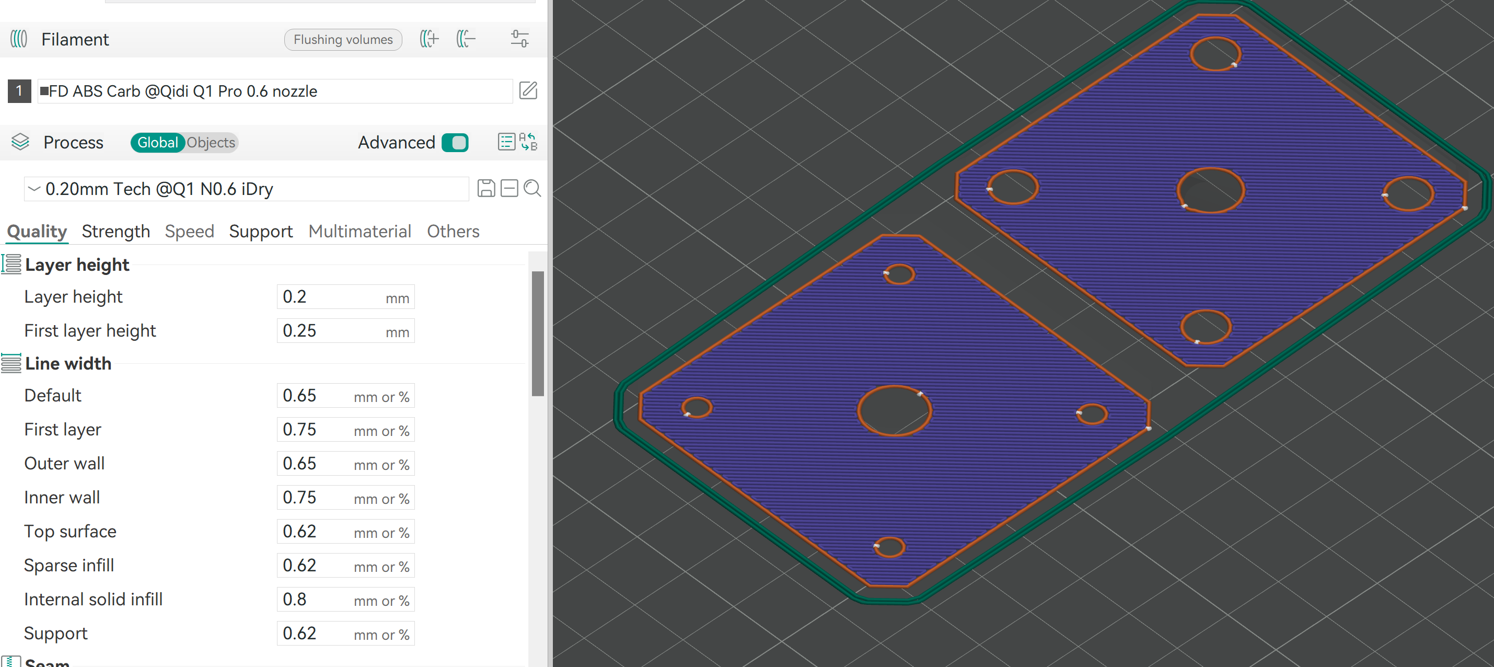
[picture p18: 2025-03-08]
User-mods/hardware/Flip Filament Out Mod/Img/layer-height.png

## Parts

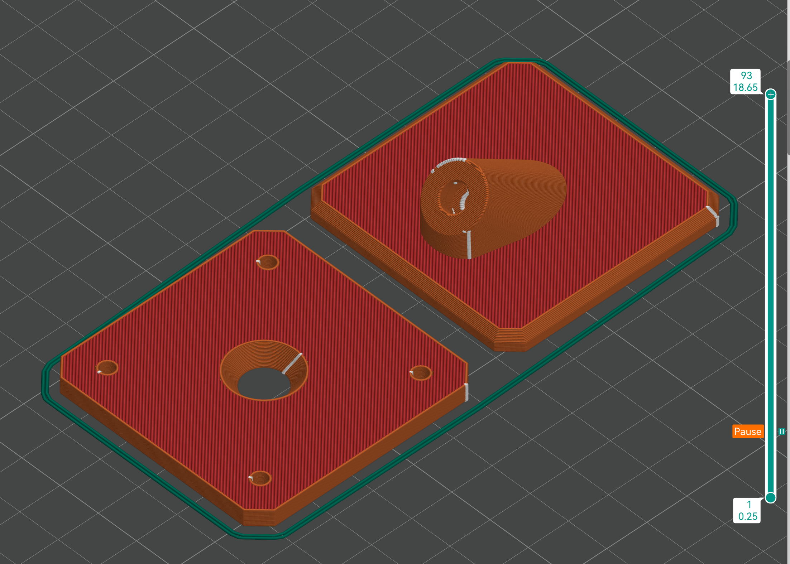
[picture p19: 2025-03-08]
User-mods/hardware/Flip Filament Out Mod/Img/arrangement-of-parts-on-bed.png

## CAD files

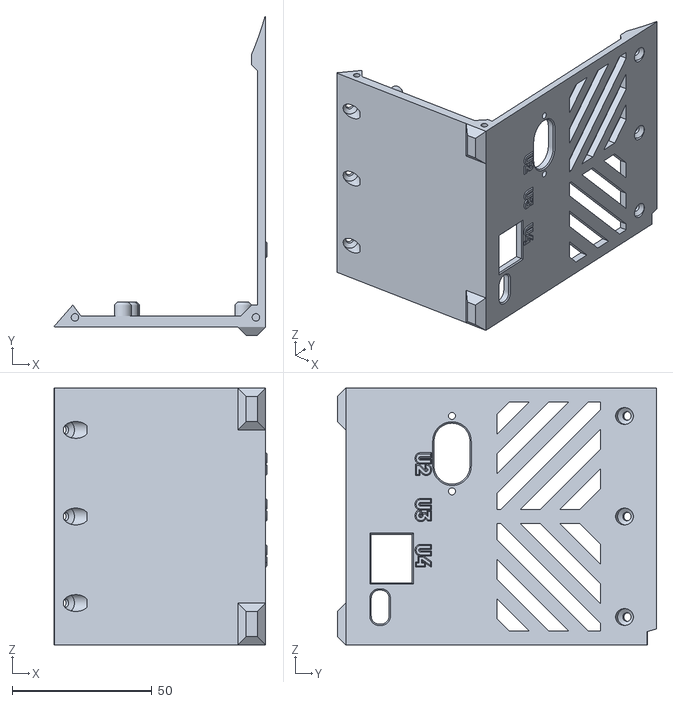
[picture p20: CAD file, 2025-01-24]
CAD/UNIT Back Cover 2.stl
76.1 x 114.2 x 92.0

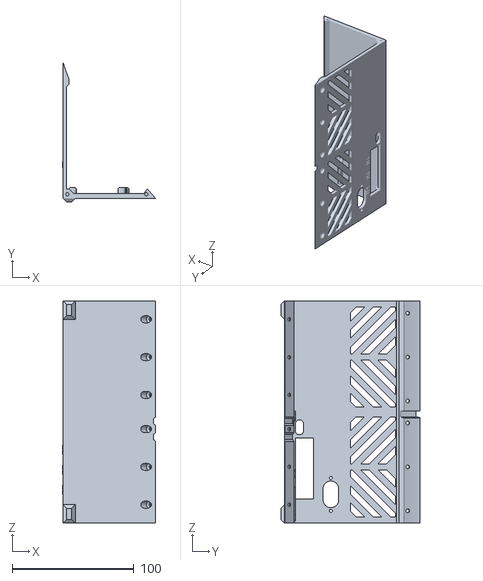
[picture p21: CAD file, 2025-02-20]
CAD/v3/UNIT MCU duo Back Cover.stl
76.1 x 114.2 x 182.0

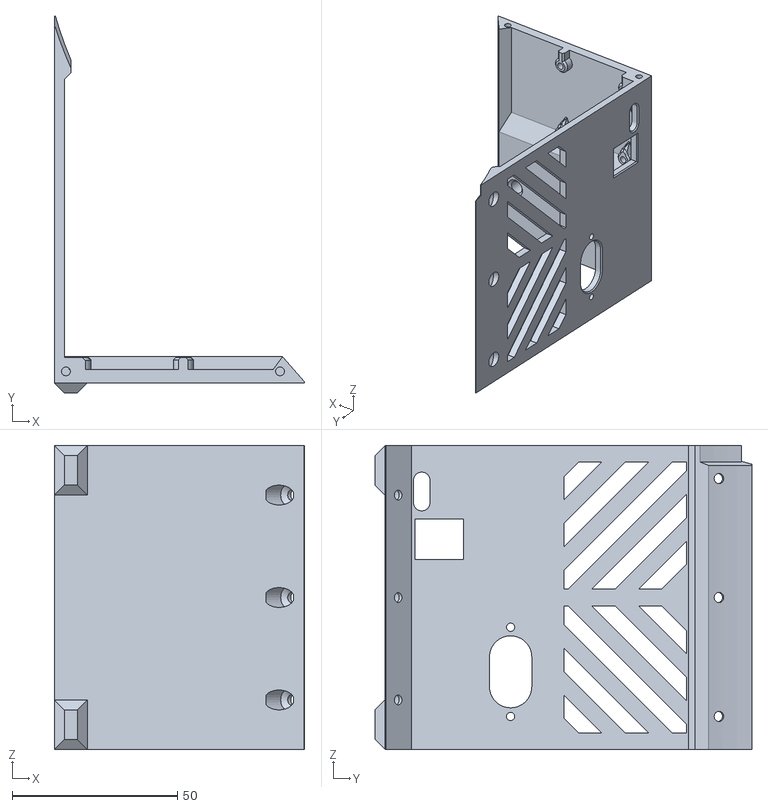
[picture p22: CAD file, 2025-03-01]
User-mods/hardware/EBB42 mod/models/EBB42_SSR-40_DA_Electronic_cover.stl
75.7 x 114.0 x 92.0

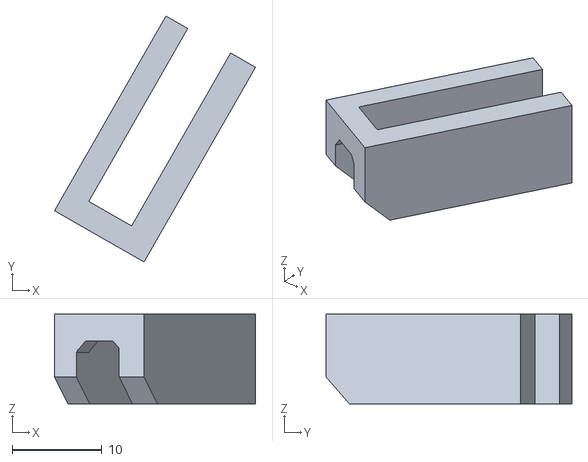
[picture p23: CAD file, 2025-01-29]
User-mods/hardware/Extreme mod/models/UNIT Extreme heater spacer Left.stl
22.4 x 27.4 x 10.0

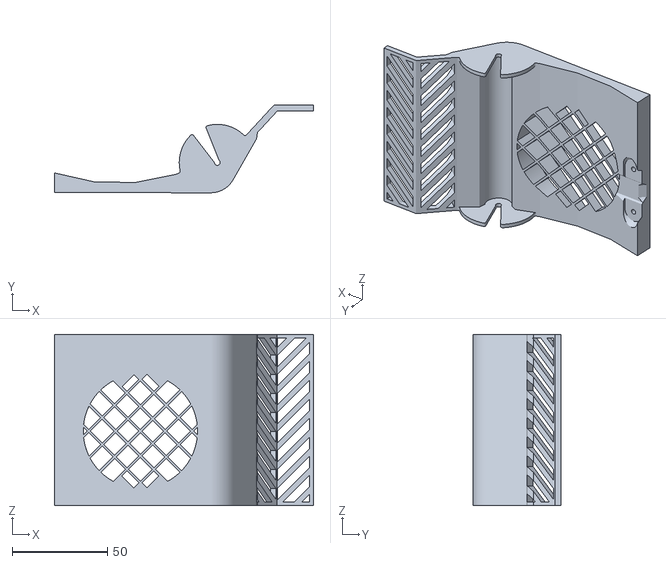
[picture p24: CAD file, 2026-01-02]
User-mods/hardware/Fan cover with spool stops/Fan cover with spool stops.stl
136.0 x 46.0 x 90.0

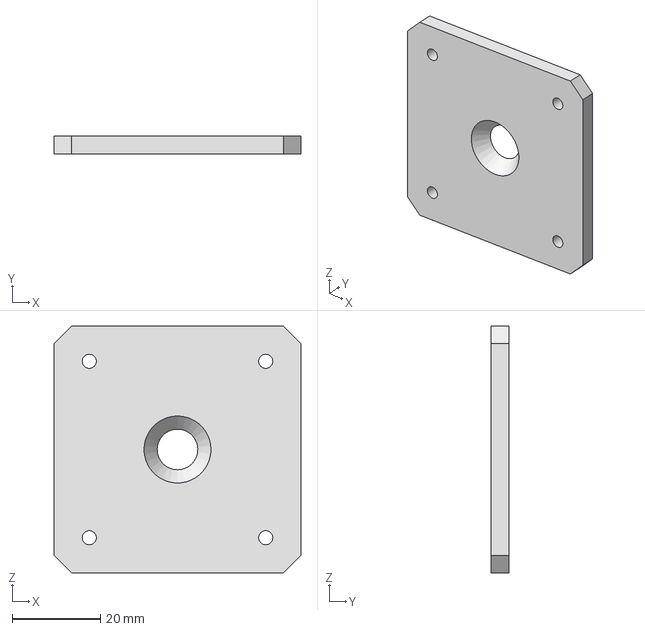
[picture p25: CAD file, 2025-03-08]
User-mods/hardware/Flip Filament Out Mod/Models/STP/Base-Mag10x2.7.step
56.0 x 4.00 x 56.0 mm

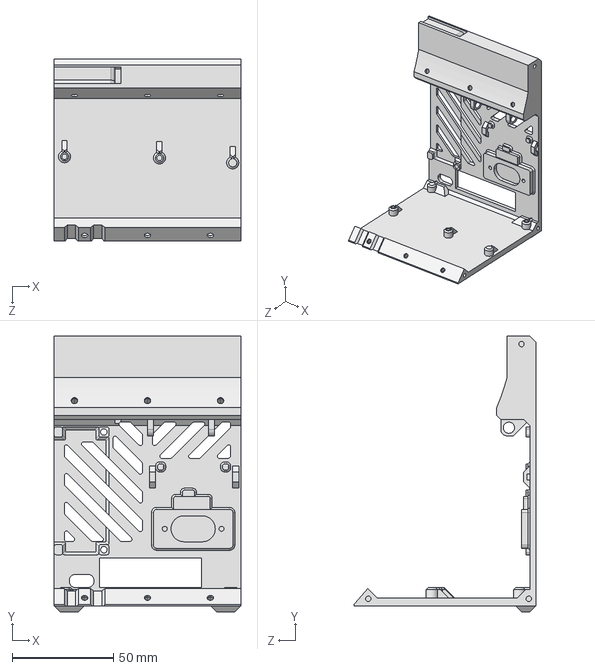
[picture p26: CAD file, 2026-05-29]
User-mods/hardware/OPi Zero 2W Mod/models/EE_BackCover.STEP
92.0 x 136.0 x 89.6 mm

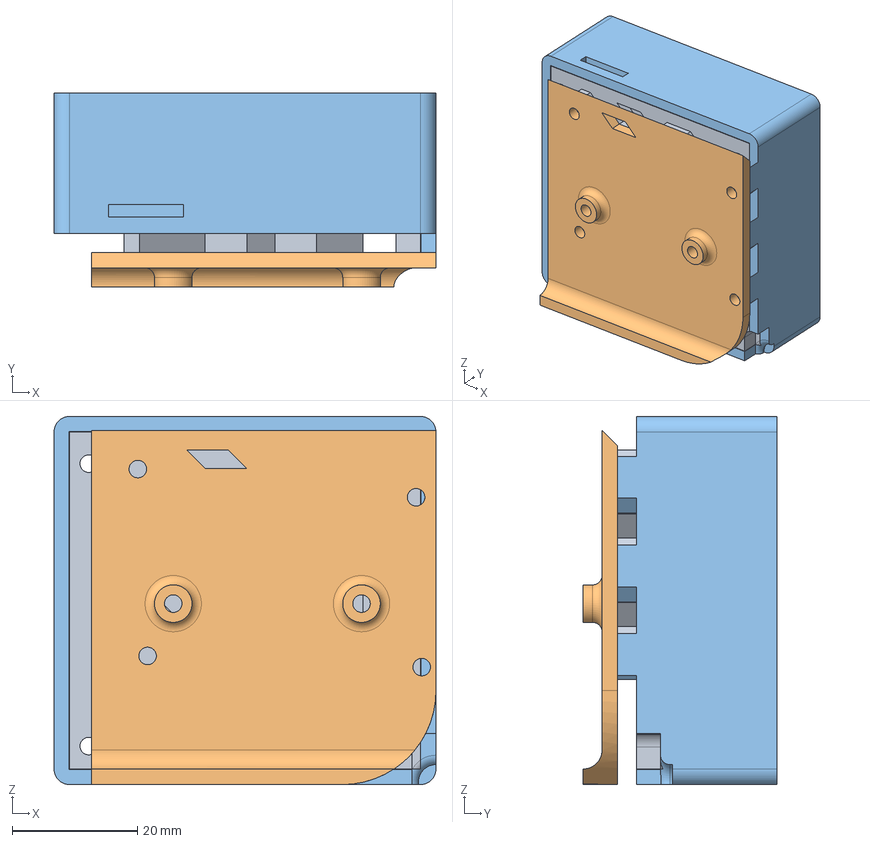
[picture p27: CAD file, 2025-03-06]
User-mods/hardware/OrangePi Zero 3 backpack/models/OrangePi Zero 3 backpack v15.step
61.0 x 30.9 x 58.8 mm

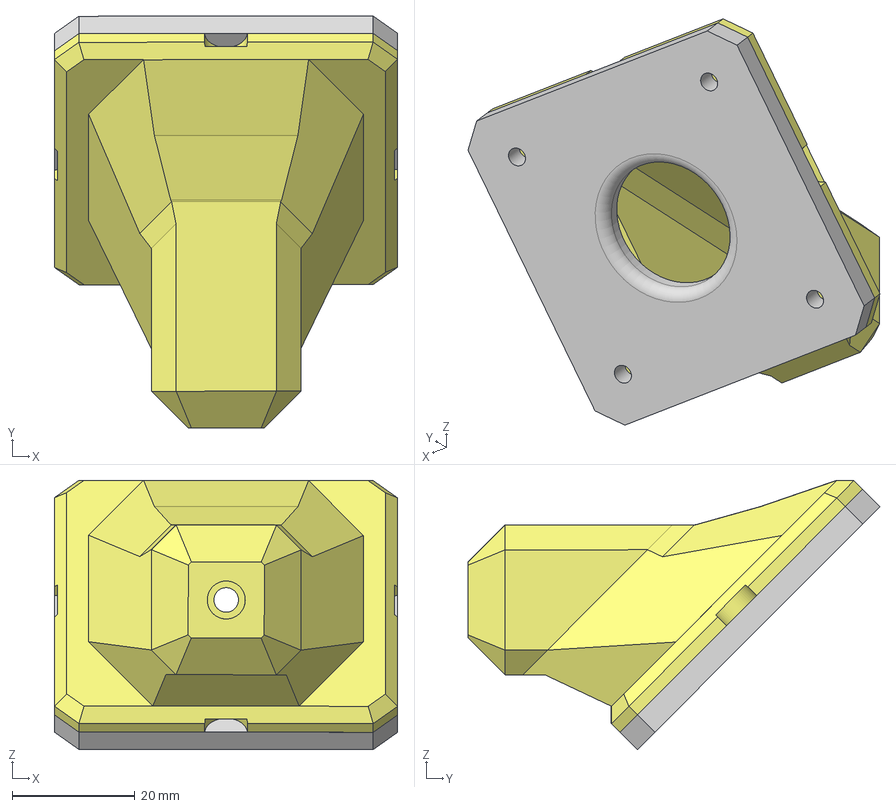
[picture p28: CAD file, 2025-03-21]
User-mods/hardware/Output of filament with a filter/models/Output Filament v9.step
56.0 x 67.2 x 43.9 mm

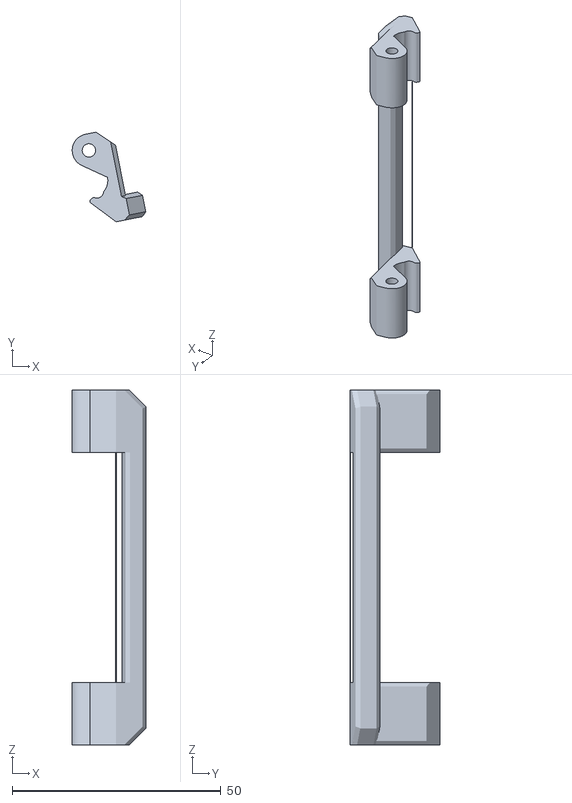
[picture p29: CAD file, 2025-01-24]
CAD/UNIT Latch Handle.stl
17.6 x 21.5 x 85.0

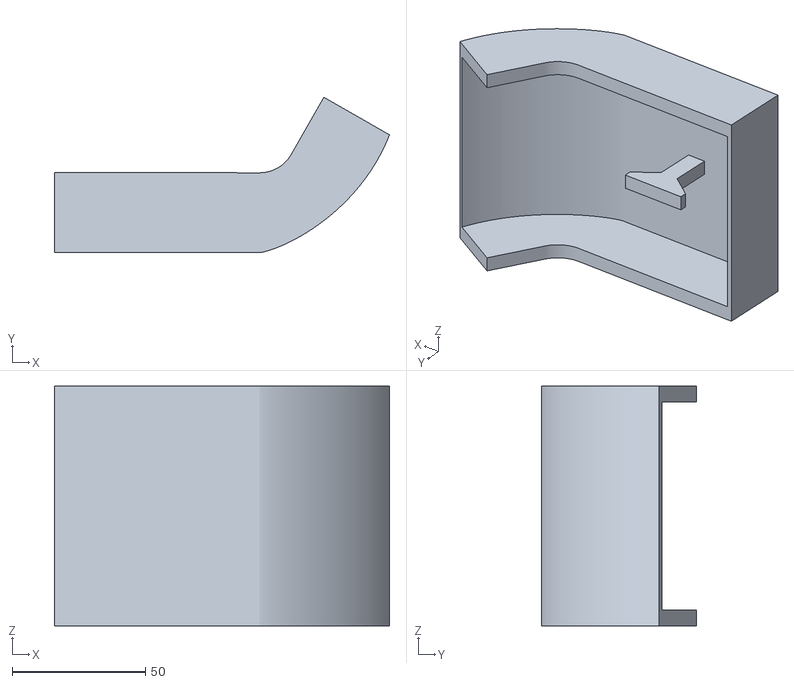
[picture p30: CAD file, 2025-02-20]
CAD/v3/UNIT duo silica tray.stl
125.7 x 58.3 x 90.0

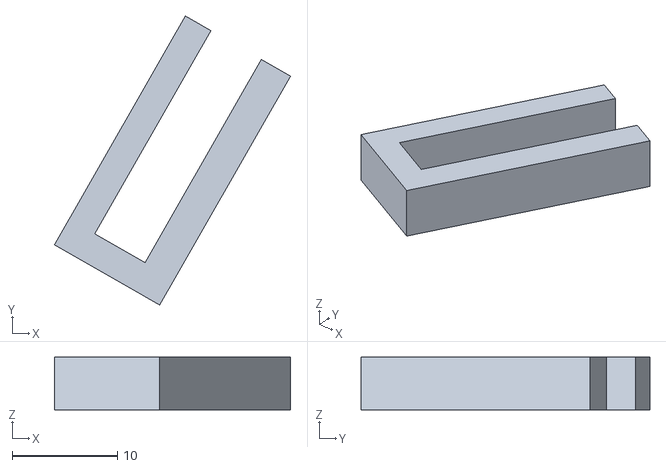
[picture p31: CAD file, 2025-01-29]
User-mods/hardware/Extreme mod/models/UNIT Extreme heater spacer Right.stl
22.4 x 27.4 x 5.00

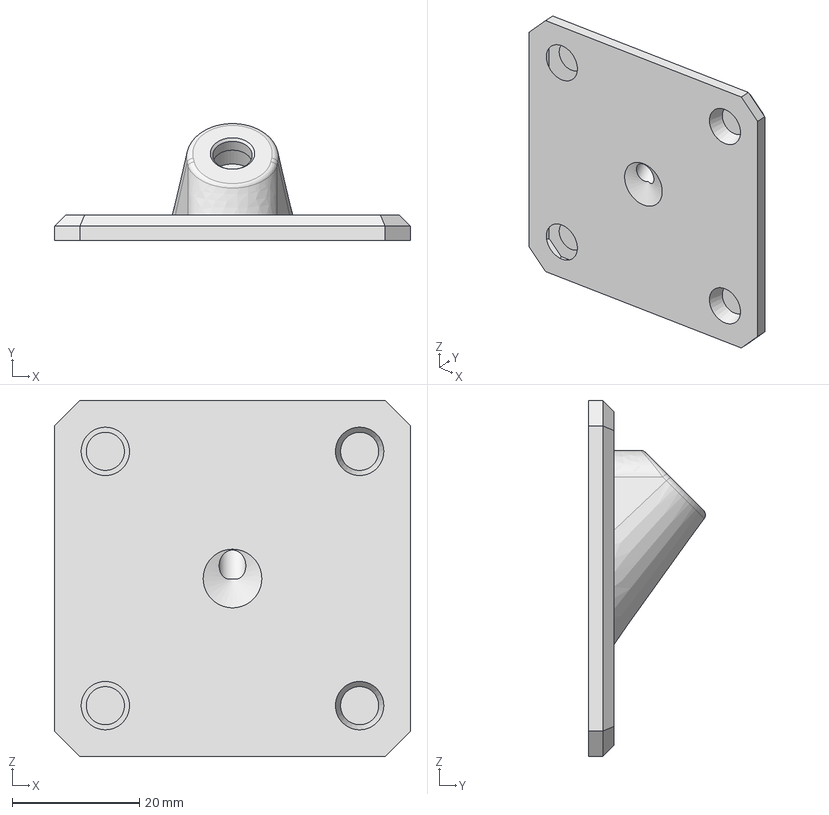
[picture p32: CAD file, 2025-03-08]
User-mods/hardware/Flip Filament Out Mod/Models/STP/FilaOut-Mag10x2.7.step
56.0 x 18.4 x 56.0 mm

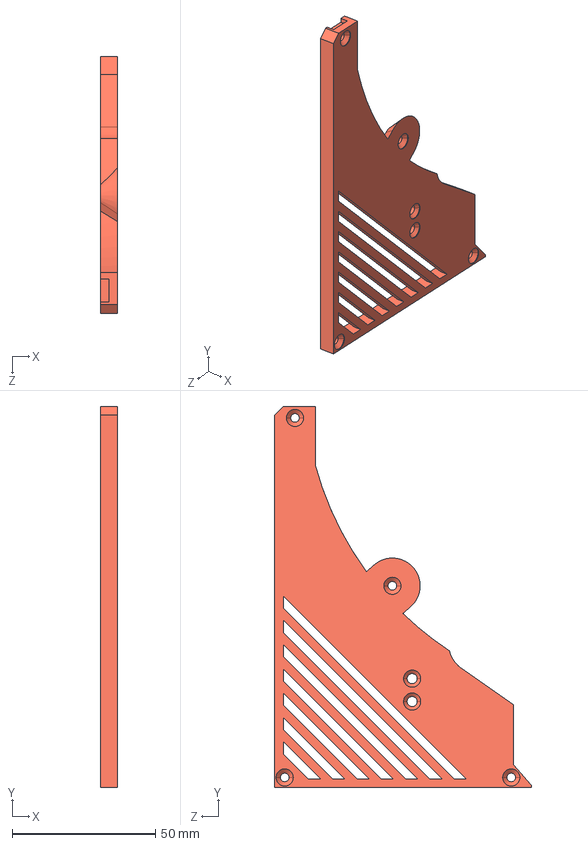
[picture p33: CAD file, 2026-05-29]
User-mods/hardware/OPi Zero 2W Mod/models/EE_Side_L.STEP
6.00 x 133.0 x 89.6 mm

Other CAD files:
User-mods/hardware/UART mod/models/Крышка Электроники (U2+U3).stp
User-mods/hardware/Output of filament with a filter/models/Output Filament v9.3.3mf
CAD/UNIT Back Cover.stl
User-mods/hardware/Output of filament with a filter/models/Clean Cartrige v2.step
CAD/OLD/NameplateUNIT.3mf
CAD/OLD/Set1.3mf
CAD/OLD/Set2.3mf
CAD/OLD/UNIT Back Cover.stl
CAD/OLD/UNIT Cover.stl
CAD/OLD/UNIT Damper Damper.stl
CAD/OLD/UNIT Damper Lower Housing.stl
CAD/OLD/UNIT Damper Upper Housing.stl
CAD/OLD/UNIT Filament Outlet.stl
CAD/OLD/UNIT Floor Sensor Retainer.stl
CAD/OLD/UNIT Floor.stl
CAD/OLD/UNIT Foot.stl
CAD/OLD/UNIT Latch.stl
CAD/OLD/UNIT Left Cover.stl
CAD/OLD/UNIT Logo Plate.stl
CAD/OLD/UNIT Name Plate 1.stl
CAD/OLD/UNIT Name Plate 2.stl
CAD/OLD/UNIT Name Plate 3.stl
CAD/OLD/UNIT Name Plate 4.stl
CAD/OLD/UNIT Right Cover.stl
CAD/UNIT Cover.stl
CAD/UNIT Damper Damper.stl
CAD/UNIT Damper Lower Housing.stl
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

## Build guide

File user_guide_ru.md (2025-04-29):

## **Руководство пользователя по настройке iDryer Unit**

### ⚠ Внимание! Работы с электрооборудованием повышенной опасности ⚠
Перед началом работы внимательно ознакомьтесь с мерами безопасности!

iDryer Unit содержит компоненты, работающие под высоким напряжением (220 В), а также открытые нагревательные элементы. Неправильное подключение или эксплуатация может привести к поражению электрическим током, возгоранию или выходу устройства из строя.

### **Подготовка к сборке**
Перед началом сборки необходимо выполнить следующие шаги:

- Убедиться в наличии всех комплектующих.
- Проверить подгонку всех деталей, особенно сопряжение движущихся частей.
- Убедиться в плавности и равномерности движения всех подвижных механизмов.

### **Предварительная проверка системы**
Рекомендуется сначала собрать всю систему **на столе**, без монтажа в корпус, и провести тестирование:

- Подключить все компоненты.
- Проверить работоспособность нагревателя, вентилятора, сервопривода заслонки и датчиков температуры.
- Подключить систему к **Klipper** и убедиться в корректной работе макросов.

После успешного тестирования можно монтировать комплектующие в корпус.
При финальной сборке укоротите провода датчиков и питания до минимально необходимой длины. 

---
## Установка необходимых файлов

   - Скопируйте файлы `rp2040_pin_aliases.cfg`, `iDryer.cfg` и другие конфигурационные файлы в директорию конфигурации Klipper.

### Файлы конфигурации
!!! success "📁 Файлы конфигурации"

    **[printer](printer.cfg)** | 
    **[iDryer](iDryer.cfg)** | 
    **[alias](rp2040_pin_aliases.cfg)** | 
    **[U1](U1.cfg)** | 
    **[U2](U2.cfg)** | 
    **[U3](U3.cfg)** | 
    **[U4](U4.cfg)** | 

По умолчанию подключен U1, однако вы можете подключить дополнительные модули, такие как U2, U3, U4, добавив соответствующие конфигурационные файлы:

```ini
[include U1.cfg]
[include U2.cfg]
[include U3.cfg]
[include U4.cfg]
```
Таким образом, система может быть расширена для управления несколькими сушилками. iDryer может быть настроен как отдельный экземпляр Klipper, установленный на Raspberry Pi, для независимой работы или как второй MCU, подключённый к основной плате принтера и использующий один экземпляр Klipper:

```ini
[mcu iDryer]
serial: /dev/serial/by-id/usb-Klipper_rp2040_DE63581213745233-if00
```

## Использование второго MCU в Klipper

Если ваше устройство подключено к Klipper как вторая MCU (например, дополнительная плата iDryer Unit), необходимо учитывать следующее:

- У второго микроконтроллера своё собственное имя в конфигурации (например, `iDryer`).
- При обращении к его пинам необходимо указывать имя MCU перед именем пина через двоеточие.

### Пример

Если устройство используется как основной MCU:

```ini
[heater_generic iDryer_U1_Heater]
heater_pin: H_U1
sensor_pin: T_U1
```

Если устройство используется как второй MCU:

```ini
[heater_generic iDryer_U1_Heater]
heater_pin: iDryer:H_U1
sensor_pin: iDryer:T_U1
```

Важно: Нужно добавить префикс `iDryer:` перед всеми пинами, относящимися ко второму контроллеру.

### Где нужно менять имя MCU

При использовании второго микроконтроллера убедитесь, что префикс добавлен во всех секциях, где используются его пины:

- `[heater_generic]`
- `[temperature_sensor]`
- `[output_pin]`
- `[fan]`
- `[gpio]`
- И других, где есть доступ к пинам.

### Как узнать имя второго MCU

Имя второго MCU задаётся в секции `[mcu]`:

```ini
[mcu iDryer]
serial: /dev/serial/by-id/usb-Klipper_iDryer_Unit123456-if00
```

Тут `iDryer` — это имя, которое нужно использовать перед пинами (`iDryer:H_U1`, `iDryer:T_U1` и т.д.).

### Краткое правило

Если пин принадлежит второму микроконтроллеру, обязательно пишите его через `ИмяMCU:Пин`.

## Настройка оборудования

### Настройка нагревателя

```ini
[heater_generic iDryer_U1_Heater]
heater_pin: H_U1
# if your iDryer is used as a second MCU use
# heater_pin: iDryer:H_U1
# and change everywhere!
max_power: 1
sensor_type: NTC 100K MGB18-104F39050L32 #Generic 3950
sensor_pin: T_U1
control: pid
pwm_cycle_time: 0.3
min_temp: 0
max_temp: 120
pid_Kp=32.923
pid_Ki=5.628
pid_Kd=48.150
```

### Настройка вентилятора

```ini
[heater_fan Fan_U1]
fan_speed: 1
pin: FAN_U1
#pin: iDryer:FAN_U1
heater: iDryer_U1_Heater
heater_temp: 55
```

### Настройка датчиков температуры и влажности

Вы можете использовать любой датчик температуры и влажности, поддерживаемый Klipper. В примере используется датчик **SHT3X**, подключённый через интерфейс I2C. Датчики для сушилок U1 и U2 подключены к одной шине I2C, а датчики для сушилок U3 и U4 подключены к другой шине I2C. Адреса датчиков на каждой шине должны отличаться:

```ini
[temperature_sensor iDryer_U1_Air]
i2c_mcu: iDryer
sensor_type: SHT3X
i2c_bus: i2c0f
i2c_address: 68
```

**Примечание:** Если вы используете другой датчик температуры или влажности, проверьте документацию Klipper для соответствующей конфигурации.

## **Финальная настройка системы**
### **Калибровка PID-регулятора нагревателя**
Перед эксплуатацией необходимо откалибровать **PID-регулятор** нагревателя.

- **Рекомендуемая температура сушки**: **90°C**.
- В конфигурации `iDryer.cfg` уже есть предварительные настройки PID, но рекомендуется провести **автокалибровку** для адаптации к конкретной системе.
  
**Калибровка:**

При закрытой крышке сушилки:
1. Открыть консоль Klipper.
2. Выполнить команду:
   ```
   PID_CALIBRATE HEATER=iDryer_U1_Heater TARGET=100
   ```
3. Дождаться завершения калибровки.
4. Записать полученные коэффициенты **Kp, Ki, Kd** в конфиг iDryer.cfg.

Пример секции нагревателя в `iDryer.cfg`:
```ini
[heater_generic iDryer_U1_Heater]
heater_pin: H_U1
max_power: 1
sensor_type: NTC 100K MGB18-104F39050L32
sensor_pin: T_U1
control: pid
pwm_cycle_time: 0.3
min_temp: 0
max_temp: 125
pid_Kp=29.625
pid_Ki=0.945
pid_Kd=232.186
```

---

### **Настройка параметра "variable_delta_high"**
Переменная `variable_delta_high` управляет разницей температур между нагревателем и камерой.

- **Начальное значение variable_delta_high:** 15°C
- Для корректной настройки:
  1. Установить `variable_delta_high=15`.
  2. Включить нагрев макросом `PA_U1`.
  3. Дождаться выхода температуры нагревателя на плато.
  4. Проверить температуру в камере:
      - **Если в камере 90°C** – необходимо оставить текущее значение `variable_delta_high`.
      - **Если температура ниже** – необходимо увеличить `variable_delta_high`.
  5. Для тестирования оставить сушилку работать **30 минут**, затем проверять состояние нагревателя **каждые 30–60 минут**.

**Важно!**  
Если нагреватель **прилипает к пластику**, значит, пластик не выдерживает температуру – необходимо снизить `variable_delta_high` перепечатать корпус други филаментом или изменить конструкцию крепления нагревателя.

**Отключение нагрева** - макрос OFF_U1

---

### **Настройка сервопривода заслонки**
Сервопривод управляет вентиляцией сушильной камеры.  

#### **Основные принципы работы серво**
- Серво управляется **ШИМ-сигналом**.
- Разные сервоприводы могут по-разному реагировать на одно и то же "ШИМ-значение".
- Настройка сервопривода должна быть **индивидуальной**.

#### **Настройка крайних положений заслонки**
1. **Не прикручивать заслонку к корпусу на первом этапе настройки**.
2. Определить **максимальные и минимальные** углы вращения серво:
   ```
   SET_SERVO SERVO=srv_U1 ANGLE=0
   ```
   ```
   SET_SERVO SERVO=srv_U1 ANGLE=90
   ```
3. Если серво упирается в корпус – скорректировать диапазон.

#### **Настройка в конфигурации**
В файле `iDryer.cfg` настроить:
```ini
[servo srv_U1]
pin: SRV_U1
maximum_servo_angle: 180
minimum_pulse_width: 0.00055
maximum_pulse_width: 0.002
```
Скорректировать значения углов variable_servo_open_angle и variable_servo_closed_angle : 

```
[gcode_macro DRY_U1]
variable_temp: 5
variable_humidity: 5
variable_duration: 5
variable_delta_high: 30
variable_servo_angle: 0
variable_servo_open_angle: 40 #degrees
variable_servo_closed_angle: 94 #degrees
variable_servo_open_time: 10 #second
variable_servo_closed_time: 300 #second
variable_data: {}
```

---

#### **Коррекция питания сервопривода**
Если используется несколько сервоприводов и возникают проблемы, рекомендуется воспользоваться **активным USB-хабом**.

Решение:
1. **Ограничение тока через резистор**  
   - Установить **резистор 4–10 Ом** в разрыв питания серво.
   - На платах 3-й ревизии установлены такие резисторы, но необходимое сопротивление может отличаться
   - Это поможет снизить пиковую нагрузку на USB порт хоста.
2. **Использование активного хаба**  
   - Подключение через USB-хаб с отдельным питанием поможет избежать перегрузки хост-системы.

---

## **Дополнительные рекомендации**
- Контролируйте показания температуры и влажности через Klipper.
- Следите за состоянием компонентов в процессе работы.
- При необходимости доработайте крепления заслонки и нагревателя.

---

## Описание работы системы
### Макросы G-кода

Для управления процессом сушки с возможностью установки температуры для разных материалов, используйте следующие макросы:

```ini
[gcode_macro OFF_U1]
gcode:
    UPDATE_DELAYED_GCODE ID=_UPDATE_U1 DURATION=0
    UPDATE_DELAYED_GCODE ID=_TOGGLE_SERVO_U1 DURATION=0
    SET_HEATER_TEMPERATURE HEATER=iDryer_U1_Heater TARGET=0

[gcode_macro PLA_U1]
variable_unit_temp: 55
variable_unit_duration: 180
gcode:
    DRY_U1 UNIT_TEMPERATURE={unit_temp} HUMIDITY=10 TIME={unit_duration}

[gcode_macro PETG_U1]
variable_unit_temp: 65
variable_unit_duration: 240
gcode:
    DRY_U1 UNIT_TEMPERATURE={unit_temp} HUMIDITY=10 TIME={unit_duration}

[gcode_macro TPU_U1]
variable_unit_temp: 60
variable_unit_duration: 300
gcode:
    DRY_U1 UNIT_TEMPERATURE={unit_temp} HUMIDITY=10 TIME={unit_duration}

[gcode_macro ABS_U1]
variable_unit_temp: 80
variable_unit_duration: 240
gcode:
    DRY_U1 UNIT_TEMPERATURE={unit_temp} HUMIDITY=10 TIME={unit_duration}

[gcode_macro PA_U1]
variable_unit_temp: 90
variable_unit_duration: 240
gcode:
    DRY_U1 UNIT_TEMPERATURE={unit_temp} HUMIDITY=10 TIME={unit_duration}

```

### Макрос для обновления данных:

```ini
[delayed_gcode _UPDATE_U1]
gcode:
    {% set unit_data = printer['gcode_macro DRY_U1'] %}
    {% set temperature = unit_data.temp %}
    {% set delta_high =  unit_data.delta_high %}
    
    # { action_respond_info("Unit_1 T: %s H: %.2f%%" %(temperature, printer["sht3x iDryer_U1_Air"].humidity))}
    
    {% if printer['temperature_sensor iDryer_U1_Air'].temperature|int > temperature|int %}
        {% set target_temp = 0|int %}
    {% elif printer['temperature_sensor iDryer_U1_Air'].temperature|int == temperature|int %}
        {% set target_temp = printer['temperature_sensor iDryer_U1_Air'].temperature|int %}
    {% elif printer['temperature_sensor iDryer_U1_Air'].temperature|int < temperature|int %}
        {% set target_temp = temperature - printer['temperature_sensor iDryer_U1_Air'].temperature + temperature + delta_high%}
        {% if target_temp > temperature + delta_high %} 
            {% set target_temp = temperature|int + delta_high|int %}
        {% endif %}
    {% endif %}
    
    SET_HEATER_TEMPERATURE HEATER=iDryer_U1_Heater TARGET={target_temp|int}
    UPDATE_DELAYED_GCODE ID=_UPDATE_U1 DURATION=1
```

### Макросы для установки температуры:

- Для ABS-пластика:

```gcode
ABS_U1
```

- Для нейлона:

```gcode
PA_U1
```

- Для поликарбоната:

```gcode
PC_U1
```

## Использование

- Установка температуры для сушки:

```gcode
DRY_UNIT1 UNIT_TEMPERATURE=60
```

- Остановка нагрева:

```gcode
iDryer_OFF  ; Отключить нагрев сушилки
```

### **Примеры команд для работы с сушилкой**
- **Выключение сушки**:
   ```gcode
   OFF_U1
   ```
- **Запуск сушки для ABS**:
   ```gcode
   ABS_U1
   ```
- **Запуск сушки для PLA**:
   ```gcode
   PLA_U1
   ```
- **Открыть заслонку вручную**:
   ```gcode
   SET_SERVO SERVO=srv_U1 ANGLE=90
   ```

---

## **Заключение**
Настройка iDryer Unit требует внимательной подгонки параметров PID, `variable_delta_high` и работы сервопривода. Если всё настроено правильно, система будет работать стабильно и эффективно, обеспечивая качественную сушку пластика.

## Альтернативный вариант алгоритма управления процессами

High End вариант от @Xatang
      
Автоматическое поддержание оптимальных параметров сушки и хранения с возможностью изменения базовых переменных и коэффициентов и информативными графиками

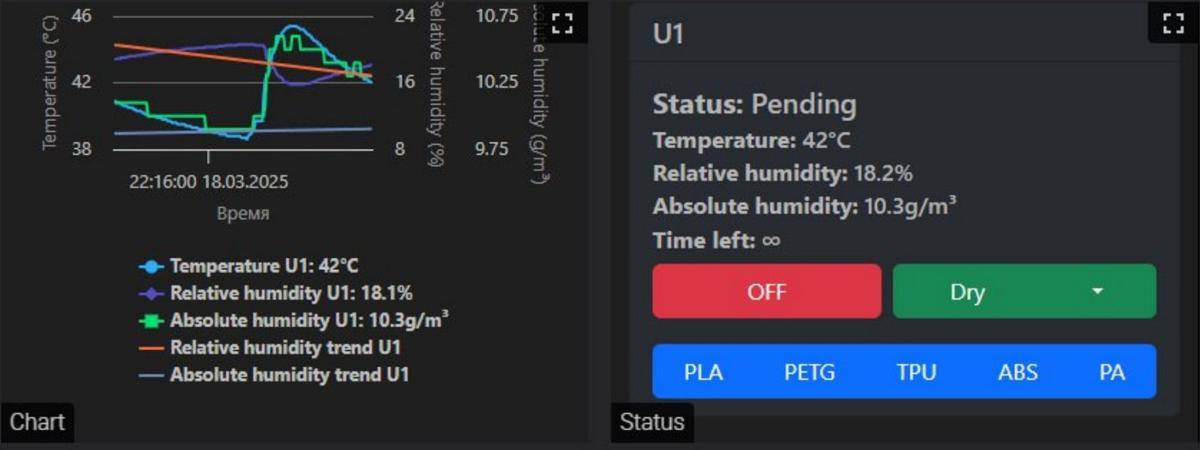
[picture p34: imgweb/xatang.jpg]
xatang


[Перейти в репозиторй проекта на GitHub](https://github.com/xatang/PyUnit)

## Общие меры предосторожности:
Отключайте устройство от сети перед любыми работами.

Не прикасайтесь к открытым токоведущим частям.

Проверяйте целостность проводки перед включением.

Не эксплуатируйте готовое устройство с поврежденным корпусом или оголенными проводами.

Не оставляйте устройство без присмотра во включенном состоянии.

Обеспечьте надежное заземление всех металлических частей корпуса.

При обнаружении запаха гари, дыма или нагрева корпуса выше нормы – немедленно отключите устройство от сети.

Избегайте попадания влаги и конденсата на элементы устройства.

**Дополнительные требования к подключению:**

Используйте автоматический выключатель или реле защиты от перегрузки.

Все соединения должны быть выполнены с соблюдением электрической изоляции.

Нарушение данных правил может привести к серьезным последствиям для жизни и здоровья!

При отсутствии опыта работы с электрооборудованием обратитесь к квалифицированному специалисту.

## Если остались вопросы:

### Связь и поддержка






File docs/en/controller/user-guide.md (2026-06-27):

# Klipper: Configuration

This page describes installing configuration files and setting up iDryer Unit in Klipper. The controller firmware must be installed first — see [Firmware Installation](firmware.md).

---

## Configuration: mcu or second_mcu

iDryer Unit connects to Klipper in two ways:

=== "mcu (standalone host)"

    iDryer Unit runs as the main MCU on a dedicated host (e.g., a Raspberry Pi for the dryer only). Config section:

    ```ini
    [mcu]
    serial: /dev/serial/by-id/usb-Klipper_rp2040_XXXXXXXXXXXXXXXX-XXXX
    ```

=== "second_mcu (shared with printer)"

    iDryer Unit connects to the printer host as a second MCU on the same Klipper instance. Config section:

    ```ini
    [mcu iDryer]
    serial: /dev/serial/by-id/usb-Klipper_rp2040_XXXXXXXXXXXXXXXX-XXXX
    ```

    In this case, all pins get the `iDryer:` prefix, e.g. `iDryer:H_U1`.

---

## Installing configuration files

### 1. Connect to the host via SSH

```bash
ssh user_name@printer_address
```

### 2. Navigate to the config directory

```bash
cd ~/printer_data/config/
```

!!! note ""
    The path may differ: `~/klipper_config/` or `~/printer_data/config/` depending on the installation version. Make sure the directory contains `printer.cfg`.

### 3. Download and run the install script

=== "mcu"

    ```bash
    wget https://raw.githubusercontent.com/pavluchenkor/iDryer-Unit/main/sh/download_iDryer_mcu.sh
    chmod +x download_iDryer_mcu.sh
    ./download_iDryer_mcu.sh
    ```

=== "second_mcu"

    ```bash
    wget https://raw.githubusercontent.com/pavluchenkor/iDryer-Unit/main/sh/download_iDryer_second_mcu.sh
    chmod +x download_iDryer_second_mcu.sh
    ./download_iDryer_second_mcu.sh
    ```

The script will create a directory with the required configuration files.

### Manual configuration file installation

If installation through the script is not possible, download the project archive from GitHub and move the required configuration files through the Fluidd or Mainsail interface.

[Download the project archive from GitHub](https://github.com/pavluchenkor/iDryer-Unit/archive/refs/heads/main.zip)

### 4. Include the config in printer.cfg

Add the following line at the top of `printer.cfg`:

=== "mcu"
    ```ini
    [include iDryer_mcu/iDryer.cfg]
    ```

=== "second_mcu"
    ```ini
    [include iDryer_second_mcu/iDryer.cfg]
    ```

### 5. Set the serial ID in iDryer.cfg

Get the controller ID:

```bash
ls /dev/serial/by-id/*
```

In `iDryer.cfg`, in the `[mcu iDryer]` section, replace the placeholder with the obtained ID:

```ini
[mcu iDryer]
serial: /dev/serial/by-id/usb-Klipper_rp2040_XXXXXXXXXXXXXXXX-XXXX
```

### 6. Connecting additional units (U2–U4)

By default, unit U1 is connected. Uncomment the required lines in `iDryer.cfg`:

```ini
[include U1.cfg]
# [include U2.cfg]
# [include U3.cfg]
# [include U4.cfg]
```

---

## Hardware configuration

### Heater

```ini
[heater_generic iDryer_U1_Heater]
heater_pin: H_U1
max_power: 1
sensor_type: NTC 100K MGB18-104F39050L32
sensor_pin: T_U1
control: pid
pwm_cycle_time: 0.3
min_temp: 0
max_temp: 120
pid_Kp: 32.923
pid_Ki: 5.628
pid_Kd: 48.150
```

### Fan

```ini
[heater_fan Fan_U1]
fan_speed: 1
pin: FAN_U1
# when using second_mcu: pin: iDryer:FAN_U1
heater: iDryer_U1_Heater
heater_temp: 55
```

### Temperature and humidity sensor

Example using SHT3X on the I2C bus:

```ini
[temperature_sensor iDryer_U1_Air]
i2c_mcu: iDryer
sensor_type: SHT3X
i2c_bus: i2c0f
i2c_address: 68  # 68 or 69
```

!!! note ""
    U1 and U2 sensors share one I2C bus; U3 and U4 share another. Sensor addresses on the same bus must differ: one set to `68`, the other to `69`. For other sensor types, refer to the [Klipper documentation](https://www.klipper3d.org/Config_Reference.html#temperature-sensors).

---

## PID calibration

Perform calibration with the dryer lid closed:

1. Open the Klipper console.
2. Run the command:
   ```
   PID_CALIBRATE HEATER=iDryer_U1_Heater TARGET=100
   ```
3. Wait for it to complete.
4. Save the obtained coefficients in `iDryer.cfg`.

---

## Damper servo configuration

### 1. Determining end positions

The servo is controlled by a PWM signal. Different servo models respond differently to the same values — configuration is always individual.

**Do not attach the damper to the enclosure** at this stage — first determine the working range.

Test end positions in the Klipper console:

```
SET_SERVO SERVO=srv_U1 ANGLE=0
SET_SERVO SERVO=srv_U1 ANGLE=90
```

If the servo hits the enclosure — adjust the range.

### 2. Saving angles to config

Check the servo section in `iDryer.cfg`:

```ini
[servo srv_U1]
pin: SRV_U1
maximum_servo_angle: 180
minimum_pulse_width: 0.00055
maximum_pulse_width: 0.002
```

In `iDryer.cfg`, in the `DRY_U1` macro, set the angles:

```ini
variable_servo_open_angle: 40    # degrees for open position
variable_servo_closed_angle: 94  # degrees for closed position
```

### 3. Servo power correction

When using multiple servos, glitches may occur due to peak load on the host USB port.

**Option 1 — resistor in the servo power line:**

Install a 4–10 Ohm resistor in the servo power supply line. Revision 3 boards already have resistors soldered, but the specific resistance must be selected individually.

**Option 2 — active USB hub:**

Connect the controller via a USB hub with its own power supply — this eliminates host port overload.

!!! note ""
    Communication stability issues (dropouts, MCU reboots) may be caused by electromagnetic interference from power wires or the fan. Solutions — ferrite filter on the USB cable and RC snubber in parallel with the fan. → [Troubleshooting](troubleshooting.md)

---

## delta_high configuration

`variable_delta_high` controls the difference between the heater temperature and the target air temperature.

Configuration procedure:

1. Set the initial value `variable_delta_high: 15`.
2. Start heating with the `PA_U1` macro.
3. Wait for the temperature to plateau.
4. Check the chamber temperature:
   - If the chamber is at 90 °C — the value is suitable.
   - If lower — increase `variable_delta_high`.
5. Let it run for 30 minutes, then check every 30–60 minutes.

!!! warning ""
    If the heater sticks to the plastic enclosure — the plastic cannot withstand the temperature. Reduce `variable_delta_high`, reprint the enclosure in ABS or ABS-CF, or change the heater mounting method.

---

## G-code macros

Use preset macros to control drying by material type:

| Macro | Temperature | Duration |
|---|---|---|
| `PLA_U1` | 55 °C | 180 min |
| `PETG_U1` | 65 °C | 240 min |
| `ABS_U1` | 80 °C | 240 min |
| `PA_U1` | 90 °C | 240 min |
| `TPU_U1` | 60 °C | 300 min |
| `OFF_U1` | off | — |

Run a custom drying mode:

```gcode
DRY_U1 UNIT_TEMPERATURE=70 HUMIDITY=10 TIME=180
```

Open/close the damper manually:

```gcode
SET_SERVO SERVO=srv_U1 ANGLE=90  ; open
SET_SERVO SERVO=srv_U1 ANGLE=0   ; close
```

---

## Alternative control algorithm — PyUnit

Community project by [@Xatang](https://github.com/xatang). Automatic maintenance of drying and storage parameters with configurable coefficients and informative graphs.

PyUnit

→ [PyUnit repository on GitHub](https://github.com/xatang/PyUnit)

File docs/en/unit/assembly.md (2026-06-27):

# Assembly

This page describes the physical assembly of the iDryer Unit enclosure and electronics.

!!! danger "Warning! High-risk electrical work"
    Before starting, carefully read the safety precautions.

    iDryer Unit contains components operating at mains voltage 110–230 V. Incorrect wiring or operation can lead to electric shock, fire, or device failure.

!!! danger "Working with mains voltage"
    All work involving connection to 110–230 V mains must be done with the device powered off. Verify that all connections are properly insulated before the first power-on. See the [Safety](safety.md) section for details.

!!! warning "General precautions"
    - Disconnect the device from mains power before any work.
    - Do not touch exposed live parts.
    - Check wiring integrity before powering on.
    - Do not operate the device with a damaged enclosure or exposed wires.
    - Do not leave the powered device unattended.
    - Ensure reliable grounding of all metal enclosure parts.
    - If you notice a burning smell, smoke, or abnormal enclosure heating, disconnect the device from mains power immediately.
    - Avoid moisture and condensation on device components.
    - Use a circuit breaker or overload protection relay.
    - All connections must be made with proper electrical insulation.
    - If you do not have experience working with electrical equipment, contact a qualified specialist.

!!! tip "Before you start"
    First, assemble the system on a bench without mounting in the enclosure and verify all components are working. Preparation instructions are in [Before Assembly](before.md).

---

## What you need

- Printed enclosure — [CAD: models and print parameters](cad.md)
- All components from the [bill of materials](before.md)
- Flashed and tested Unit MCU board

---

## Step-by-step assembly

### Steps 1–4: Main chamber

<div class="grid cards" markdown>
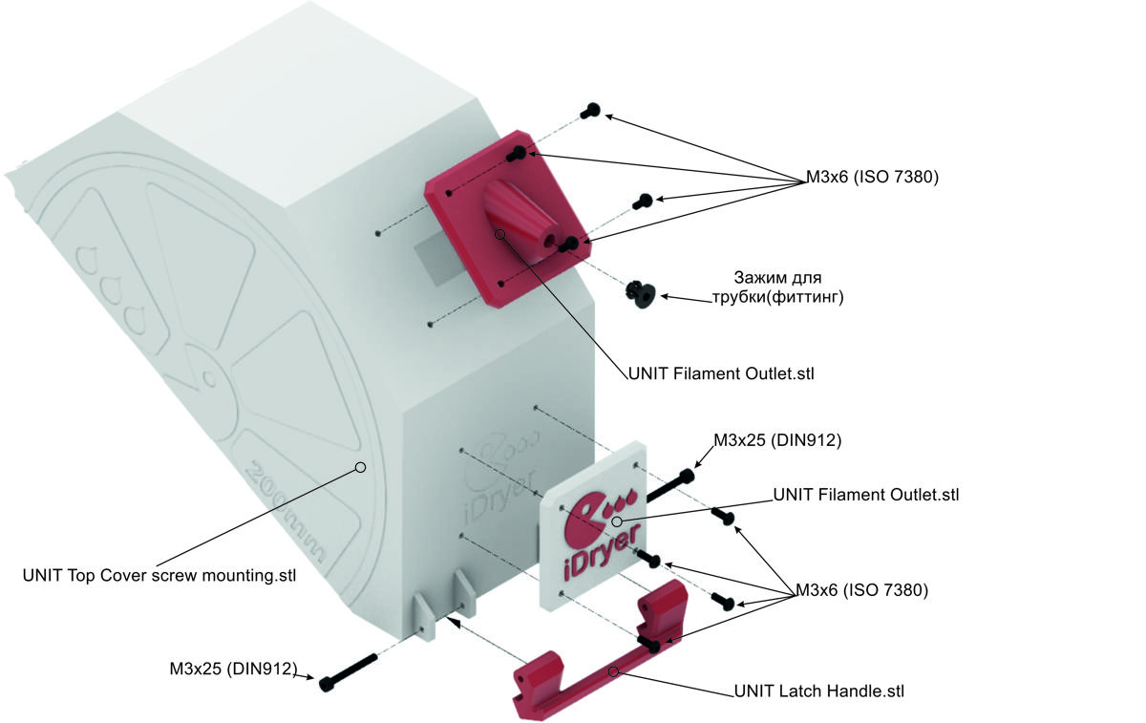
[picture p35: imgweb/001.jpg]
- 
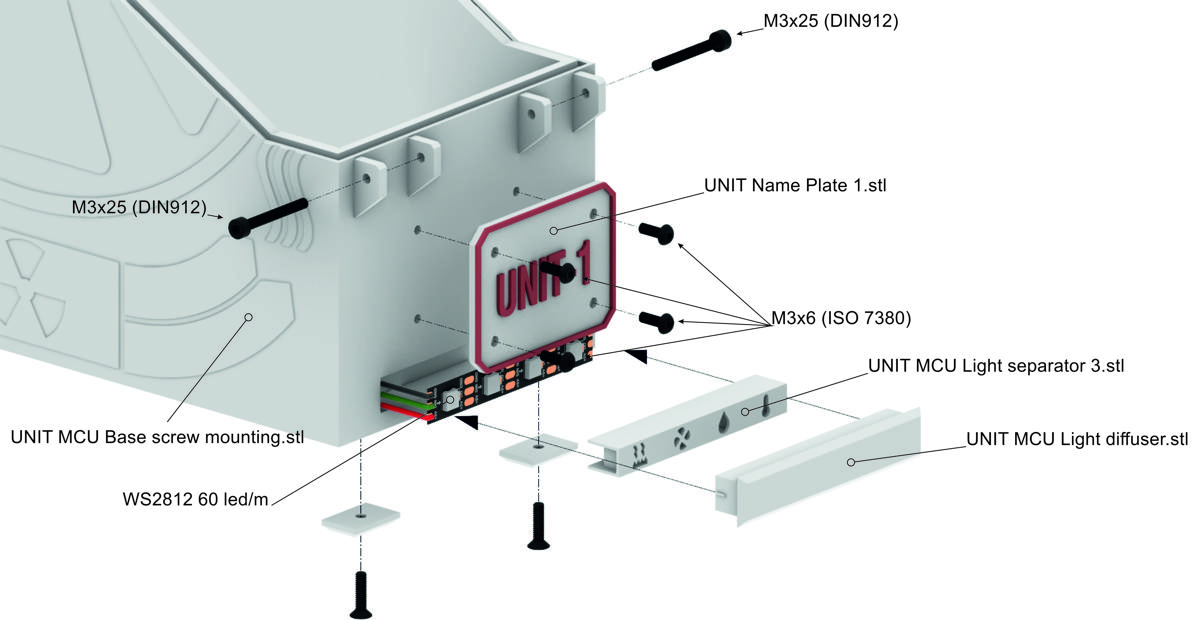
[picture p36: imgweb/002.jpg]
- 
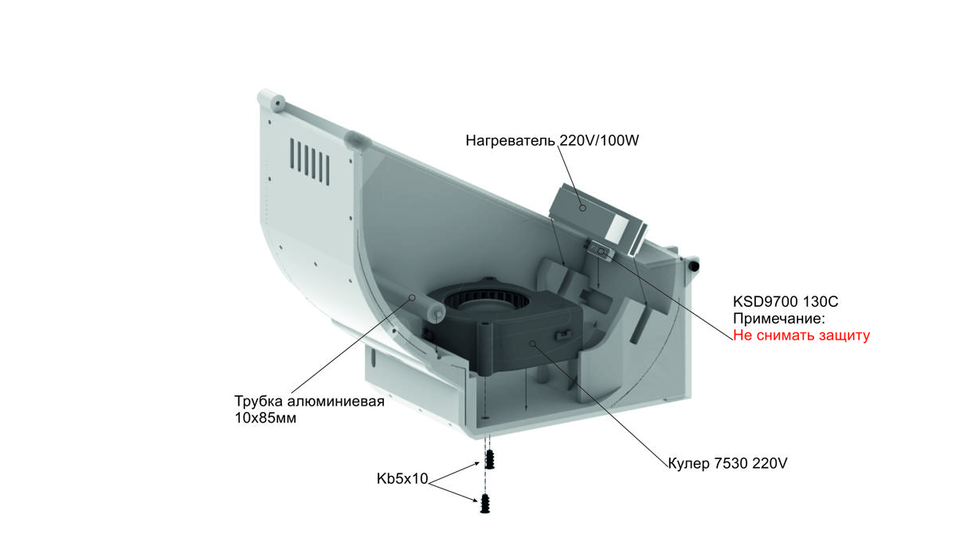
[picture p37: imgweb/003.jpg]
- 
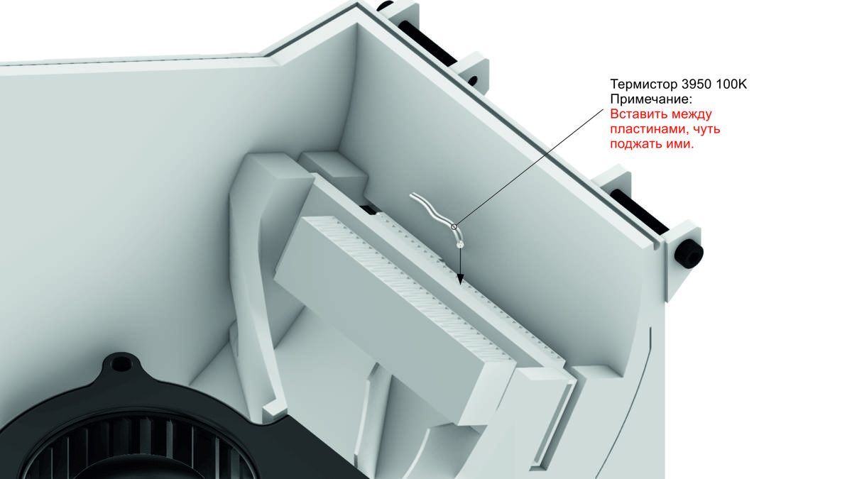
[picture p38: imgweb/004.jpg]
- 
</div>

1. Install the spool holder rollers into the enclosure base.
2. Install the heating element in the designated mounting locations.
3. Secure the heater with spacers (left + right).
4. Install the Thermal Protector KSD9700 in contact with the heater.

!!! warning "Thermal Protector KSD9700"
    Ensure tight contact between KSD9700 and the heater body. Poor contact reduces the reliability of emergency protection.

### Steps 5–7: Ventilation and damper

<div class="grid cards" markdown>
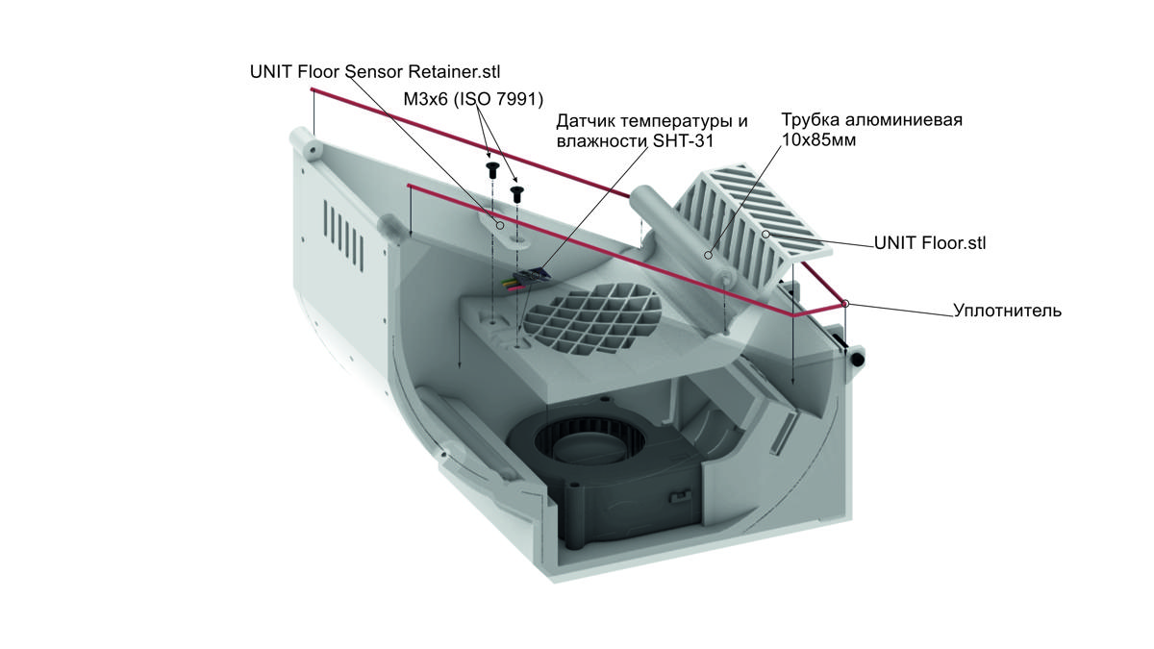
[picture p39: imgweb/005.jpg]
- 
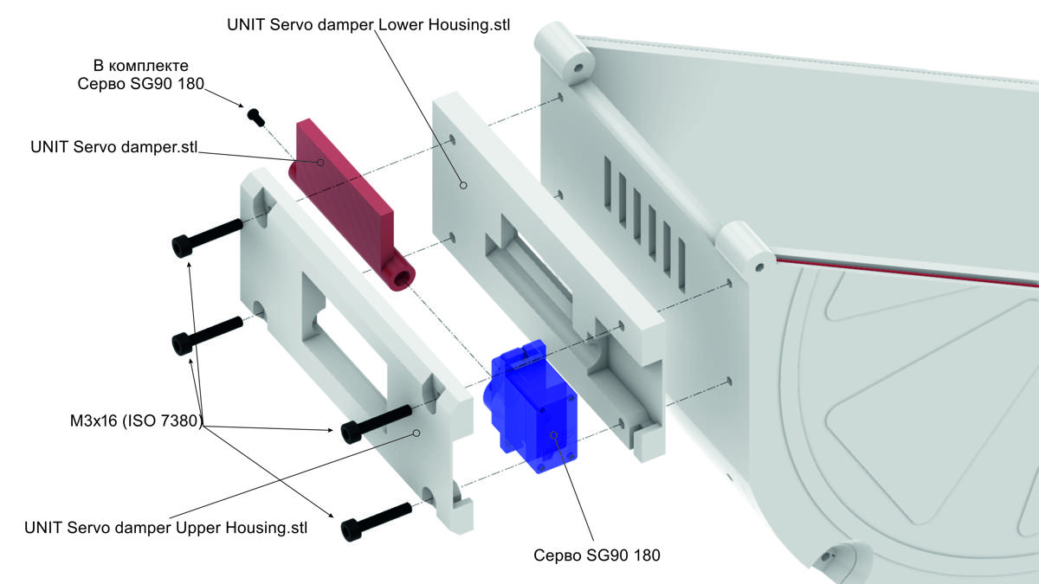
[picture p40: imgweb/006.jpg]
- 
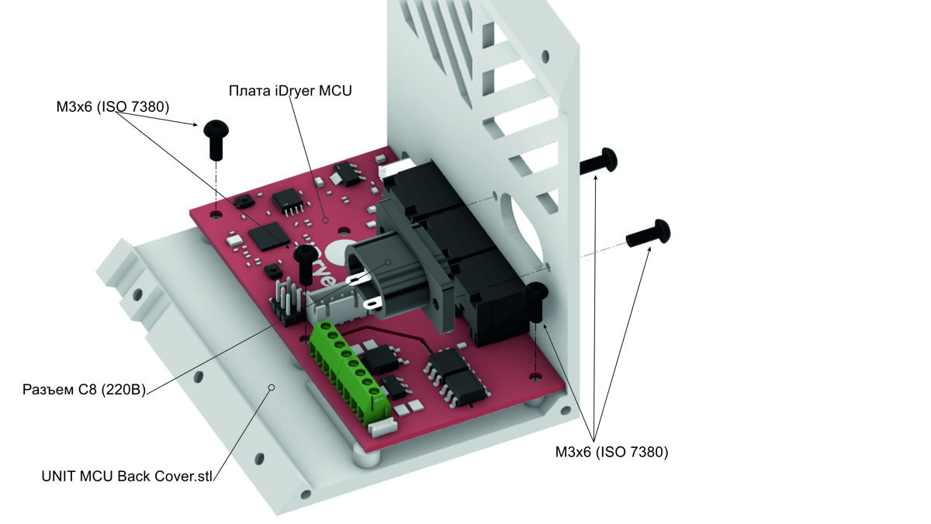
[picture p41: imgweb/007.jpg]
- 
</div>

5. Install the fan in the enclosure, secure with fasteners.
6. Assemble the damper assembly: connect the blade and damper body. Damper type depends on the servo used (3.7 g or 9 g).
7. Connect the servo to the damper. **Do not screw the damper to the enclosure at this stage** — servo angles are configured after flashing.

### Steps 8–10: Electronics compartment

<div class="grid cards" markdown>
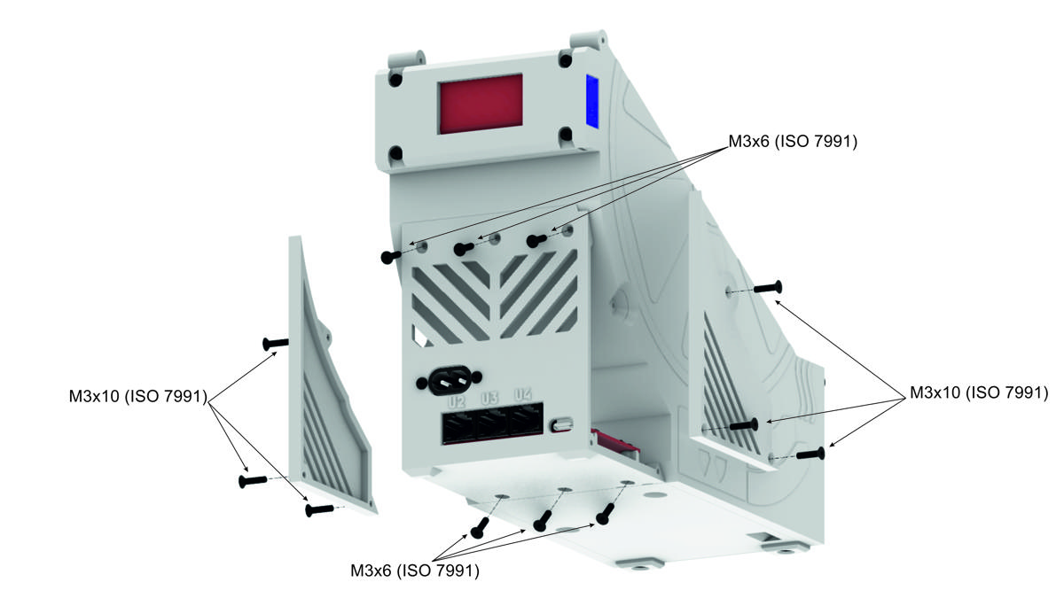
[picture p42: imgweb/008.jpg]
- 
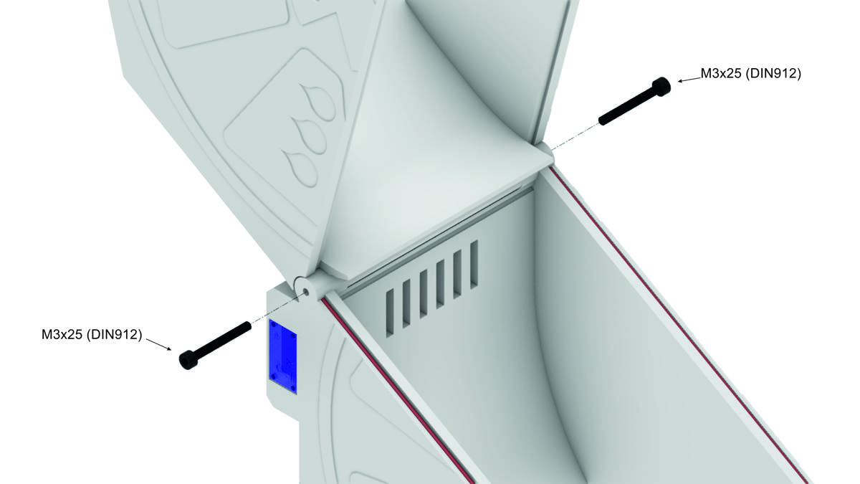
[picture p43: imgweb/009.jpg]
- 
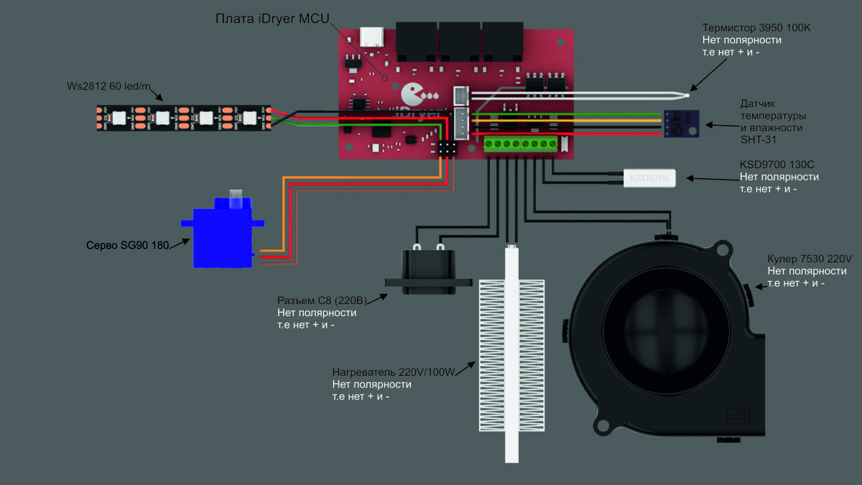
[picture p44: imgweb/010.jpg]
- 
</div>

8. Secure the control board in the electronics compartment.
9. Install and connect the power connector. Use ferrule terminals for power wires.
10. Route and secure sensor wires in the cable channel. Install the electronics compartment cover.

!!! warning "Thermistor installation"
    Install the thermistor at the edge of the heater, approximately at mid-height of the heatsink fins.

    Exposed wire ends at the thermistor base must not contact the metal heater body. If necessary, insulate these sections with Kapton tape or place them in PTFE tubing / heat shrink.

    The heater temperature may reach 140 °C.

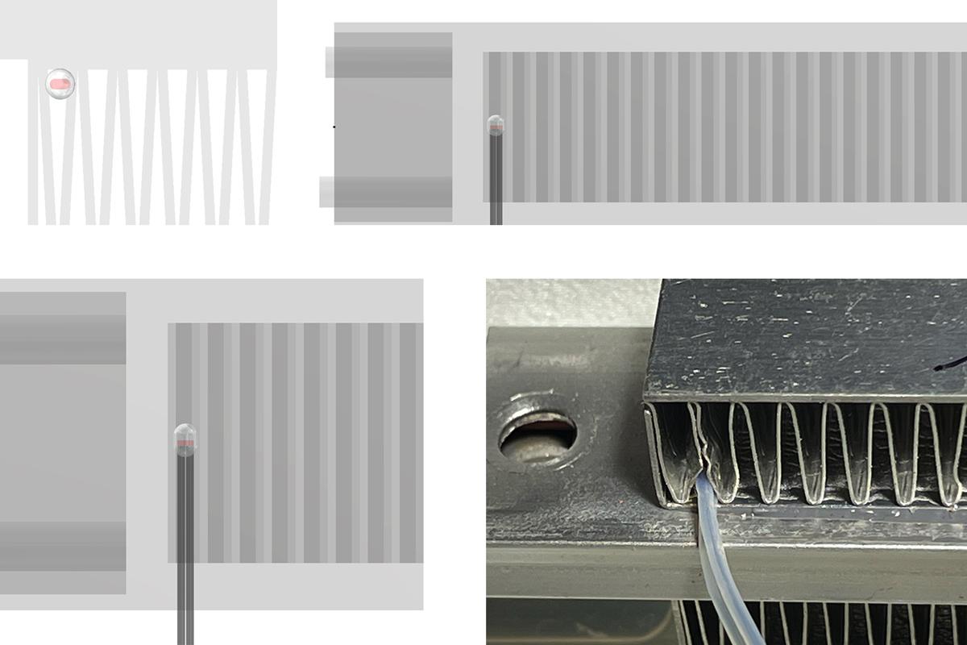
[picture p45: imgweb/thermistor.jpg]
Thermistor installation


---

## After assembly

Before the first power-on:

- [ ] Check insulation of all connections.
- [ ] Make sure wires are not pinched by covers.
- [ ] Verify the thermal cutout makes firm contact with the heater.
- [ ] Check wiring integrity with a multimeter.

Next step — firmware installation in the **[Controller](../controller/board.md)** section.

---

!!! quote "Acknowledgements"
    Many thanks to Igor (@dr_perry_coke) for his incredible work, sense of aesthetics, and the provided iDryer Unit assembly images.

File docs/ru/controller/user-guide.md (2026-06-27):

# Klipper: настройка

На этой странице описана установка конфигурационных файлов и настройка iDryer Unit в среде Klipper. Прошивка контроллера должна быть установлена заранее — см. раздел «Прошивка».

---

## Конфигурация: mcu или second_mcu

iDryer Unit подключается к Klipper двумя способами:

=== "mcu (отдельный хост)"

    iDryer Unit работает как основной MCU на отдельном хосте (например, Raspberry Pi только для сушилки). Секция в конфиге:

    ```ini
    [mcu]
    serial: /dev/serial/by-id/usb-Klipper_rp2040_XXXXXXXXXXXXXXXX-XXXX
    ```

=== "second_mcu (совместно с принтером)"

    iDryer Unit подключается к хосту принтера как второй MCU на одном экземпляре Klipper. Секция в конфиге:

    ```ini
    [mcu iDryer]
    serial: /dev/serial/by-id/usb-Klipper_rp2040_XXXXXXXXXXXXXXXX-XXXX
    ```

    В этом случае во всех пинах добавляется префикс `iDryer:`, например `iDryer:H_U1`.

---

## Установка конфигурационных файлов

### 1. Подключитесь к хосту по SSH

```bash
ssh user_name@printer_address
```

### 2. Перейдите в директорию конфигурации

```bash
cd ~/printer_data/config/
```

!!! note ""
    Путь может отличаться: `~/klipper_config/` или `~/printer_data/config/` в зависимости от версии установки. Убедитесь, что в директории находится файл `printer.cfg`.

### 3. Загрузите и запустите скрипт установки

=== "mcu"

    ```bash
    wget https://raw.githubusercontent.com/pavluchenkor/iDryer-Unit/main/sh/download_iDryer_mcu.sh
    chmod +x download_iDryer_mcu.sh
    ./download_iDryer_mcu.sh
    ```

=== "second_mcu"

    ```bash
    wget https://raw.githubusercontent.com/pavluchenkor/iDryer-Unit/main/sh/download_iDryer_second_mcu.sh
    chmod +x download_iDryer_second_mcu.sh
    ./download_iDryer_second_mcu.sh
    ```

Скрипт создаст директорию с необходимыми конфигурационными файлами.

### Ручная установка конфигурационных файлов

Если установка через скрипт невозможна, скачайте архив проекта с GitHub и перенесите нужные конфигурационные файлы через интерфейс Fluidd или Mainsail.

[Скачать архив проекта с GitHub](https://github.com/pavluchenkor/iDryer-Unit/archive/refs/heads/main.zip)

### 4. Подключите конфиг в printer.cfg

Добавьте строку в начало файла `printer.cfg`:

=== "mcu"
    ```ini
    [include iDryer_mcu/iDryer.cfg]
    ```

=== "second_mcu"
    ```ini
    [include iDryer_second_mcu/iDryer.cfg]
    ```

### 5. Укажите серийный ID в iDryer.cfg

Получите ID контроллера:

```bash
ls /dev/serial/by-id/*
```

В файле `iDryer.cfg` в секции `[mcu iDryer]` замените плейсхолдер на полученный ID:

```ini
[mcu iDryer]
serial: /dev/serial/by-id/usb-Klipper_rp2040_XXXXXXXXXXXXXXXX-XXXX
```

### 6. Подключение дополнительных блоков (U2–U4)

По умолчанию подключён блок U1. Раскомментируйте нужные строки в `iDryer.cfg`:

```ini
[include U1.cfg]
# [include U2.cfg]
# [include U3.cfg]
# [include U4.cfg]
```

---

## Настройка оборудования

### Нагреватель

```ini
[heater_generic iDryer_U1_Heater]
heater_pin: H_U1
max_power: 1
sensor_type: NTC 100K MGB18-104F39050L32
sensor_pin: T_U1
control: pid
pwm_cycle_time: 0.3
min_temp: 0
max_temp: 120
pid_Kp: 32.923
pid_Ki: 5.628
pid_Kd: 48.150
```

### Вентилятор

```ini
[heater_fan Fan_U1]
fan_speed: 1
pin: FAN_U1
# при использовании second_mcu: pin: iDryer:FAN_U1
heater: iDryer_U1_Heater
heater_temp: 55
```

### Датчик температуры и влажности

В примере используется SHT3X на шине I2C:

```ini
[temperature_sensor iDryer_U1_Air]
i2c_mcu: iDryer
sensor_type: SHT3X
i2c_bus: i2c0f
i2c_address: 68  # 68 или 69
```

!!! note ""
    Датчики U1 и U2 подключены к одной шине I2C, датчики U3 и U4 — к другой. Адреса датчиков на одной шине должны отличаться: один на `68`, другой на `69`. При использовании другого датчика сверьтесь с [документацией Klipper](https://www.klipper3d.org/Config_Reference.html#temperature-sensors).

---

## Калибровка PID

Выполните калибровку при закрытой крышке сушилки:

1. Откройте консоль Klipper.
2. Выполните команду:
   ```
   PID_CALIBRATE HEATER=iDryer_U1_Heater TARGET=100
   ```
3. Дождитесь завершения.
4. Запишите полученные коэффициенты в `iDryer.cfg`.

---

## Настройка сервопривода заслонки

### 1. Определение крайних положений

Сервопривод управляется ШИМ-сигналом. Разные модели сервоприводов по-разному реагируют на одни и те же значения — настройка всегда индивидуальна.

**Не прикручивайте заслонку к корпусу** на этом этапе — сначала определите рабочий диапазон.

Проверьте крайние положения командами в консоли Klipper:

```
SET_SERVO SERVO=srv_U1 ANGLE=0
SET_SERVO SERVO=srv_U1 ANGLE=90
```

Если сервопривод упирается в корпус — скорректируйте диапазон.

### 2. Запись углов в конфиг

Проверьте секцию сервопривода в `iDryer.cfg`:

```ini
[servo srv_U1]
pin: SRV_U1
maximum_servo_angle: 180
minimum_pulse_width: 0.00055
maximum_pulse_width: 0.002
```

В файле `iDryer.cfg` в макросе `DRY_U1` задайте углы:

```ini
variable_servo_open_angle: 40    # градусы открытого положения
variable_servo_closed_angle: 94  # градусы закрытого положения
```

### 3. Коррекция питания сервопривода

При использовании нескольких сервоприводов возможны сбои из-за пиковой нагрузки на USB-порт хоста.

**Вариант 1 — резистор в цепи питания серво:**

Установите резистор 4–10 Ом в разрыв питания сервопривода. На платах ревизии 3 резисторы уже распаяны, однако конкретное сопротивление подбирается индивидуально.

**Вариант 2 — активный USB-хаб:**

Подключите контроллер через USB-хаб с отдельным питанием — это исключает перегрузку порта хоста.

!!! note ""
    Проблемы со стабильностью связи (обрывы, перезагрузки MCU) могут быть вызваны ЭМ-помехами от силовых проводов или вентилятора. Решения — ферритовый фильтр на USB-кабель и RC-снаббер параллельно вентилятору. См. раздел «Устранение неисправностей».

---

## Настройка delta_high

`variable_delta_high` управляет разницей между температурой нагревателя и целевой температурой воздуха.

Процедура настройки:

1. Установите начальное значение `variable_delta_high: 15`.
2. Запустите нагрев макросом `PA_U1`.
3. Дождитесь выхода на плато.
4. Проверьте температуру в камере:
   - Если в камере 90 °C — значение подходит.
   - Если ниже — увеличьте `variable_delta_high`.
5. Оставьте работать 30 минут, затем проверяйте состояние каждые 30–60 минут.

!!! warning ""
    Если нагреватель прилипает к пластику корпуса — пластик не выдерживает температуру. Снизьте `variable_delta_high`, перепечатайте корпус из ABS или ABS-CF, либо измените способ крепления нагревателя.

---

## Макросы G-кода

Для управления сушкой по типу материала используйте предустановленные макросы:

| Макрос | Температура | Время |
|---|---|---|
| `PLA_U1` | 55 °C | 180 мин |
| `PETG_U1` | 65 °C | 240 мин |
| `ABS_U1` | 80 °C | 240 мин |
| `PA_U1` | 90 °C | 240 мин |
| `TPU_U1` | 60 °C | 300 мин |
| `OFF_U1` | выкл | — |

Запуск произвольного режима:

```gcode
DRY_U1 UNIT_TEMPERATURE=70 HUMIDITY=10 TIME=180
```

Открыть/закрыть заслонку вручную:

```gcode
SET_SERVO SERVO=srv_U1 ANGLE=90  ; открыть
SET_SERVO SERVO=srv_U1 ANGLE=0   ; закрыть
```

---

## Альтернативный алгоритм управления — PyUnit

Проект от участника сообщества [@Xatang](https://github.com/xatang). Автоматическое поддержание параметров сушки и хранения с настраиваемыми коэффициентами и информативными графиками.

PyUnit

→ [Репозиторий PyUnit на GitHub](https://github.com/xatang/PyUnit)

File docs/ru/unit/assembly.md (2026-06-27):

# Сборка

На этой странице описана физическая сборка корпуса и электроники iDryer Unit.

!!! danger "Внимание! Работы с электрооборудованием повышенной опасности"
    Перед началом работы внимательно ознакомьтесь с мерами безопасности.

    iDryer Unit содержит компоненты, работающие под сетевым напряжением 110–230 В. Неправильное подключение или эксплуатация может привести к поражению электрическим током, возгоранию или выходу устройства из строя.

!!! danger "Работа с сетевым напряжением"
    Все работы с подключением к сети 110–230 В выполняйте при обесточенном устройстве. Убедитесь в надёжной изоляции всех соединений перед первым включением. Подробнее — в разделе [Безопасность](safety.md).

!!! warning "Общие меры предосторожности"
    - Отключайте устройство от сети перед любыми работами.
    - Не прикасайтесь к открытым токоведущим частям.
    - Проверяйте целостность проводки перед включением.
    - Не эксплуатируйте устройство с повреждённым корпусом или оголёнными проводами.
    - Не оставляйте включённое устройство без присмотра.
    - Обеспечьте надёжное заземление всех металлических частей корпуса.
    - При запахе гари, дыме или нагреве корпуса выше нормы немедленно отключите устройство от сети.
    - Избегайте попадания влаги и конденсата на элементы устройства.
    - Используйте автоматический выключатель или реле защиты от перегрузки.
    - Все соединения должны быть выполнены с соблюдением электрической изоляции.
    - При отсутствии опыта работы с электрооборудованием обратитесь к квалифицированному специалисту.

!!! tip "Перед началом"
    Сначала соберите систему на столе без монтажа в корпус и проверьте работоспособность всех компонентов. Инструкция по подготовке — в разделе «Перед сборкой».

---

## Что понадобится

- Распечатанный корпус — [CAD: модели и параметры печати](cad.md)
- Все компоненты из списка комплектующих раздела «Перед сборкой»
- Прошитая и протестированная плата Unit MCU

---

## Пошаговая сборка

### Шаг 1–4: Основная камера

<div class="grid cards" markdown>
- 
- 
- 
- 
</div>

1. Установите ролики катушкодержателя в основание корпуса.
2. Установите нагревательный элемент в предназначенные посадочные места.
3. Зафиксируйте нагреватель проставками (левая + правая).
4. Установите Thermal Protector KSD9700 в контакт с нагревателем.

!!! warning "Thermal Protector KSD9700"
    Убедитесь в плотном контакте KSD9700 с корпусом нагревателя. Слабый контакт снижает надёжность аварийной защиты.

### Шаг 5–7: Вентиляция и заслонка

<div class="grid cards" markdown>
- 
- 
- 
</div>

5. Установите вентилятор в корпус, зафиксируйте метизами.
6. Соберите узел заслонки: соедините лопасть и корпус заслонки. Тип заслонки зависит от используемого сервопривода (3.7 г или 9 г).
7. Подключите сервопривод к заслонке. **Не прикручивайте заслонку к корпусу на этом этапе** — углы сервопривода настраиваются после прошивки.

### Шаг 8–10: Отсек электроники

<div class="grid cards" markdown>
- 
- 
- 
</div>

8. Закрепите плату управления в отсеке электроники.
9. Установите и подключите разъём питания. Используйте наконечники НШВИ для силовых проводов.
10. Проложите и закрепите провода датчиков в кабельном канале. Установите крышку отсека электроники.

!!! warning "Установка термистора"
    Устанавливайте термистор у края нагревателя, примерно на середине высоты рёбер радиатора.

    Оголённые участки проводов у основания термистора не должны касаться металлического корпуса нагревателя. При необходимости заизолируйте эти участки каптоновым скотчем или поместите в тефлоновую трубку / термоусадку.

    Температура нагревателя может достигать 140 °C.

Установка термистора

---

## После сборки

Перед первым включением:

- [ ] Проверьте изоляцию всех соединений.
- [ ] Убедитесь, что провода не защемлены крышками.
- [ ] Убедитесь в надёжном контакте термовыключателя с нагревателем.
- [ ] Проверьте целостность проводки мультиметром.

Следующий шаг — установка прошивки в разделе «Контроллер».

---

!!! quote "Благодарности"
    Огромная благодарность Игорю (@dr_perry_coke) за невероятную работу, чувство прекрасного и предоставленные изображения сборки iDryer Unit.

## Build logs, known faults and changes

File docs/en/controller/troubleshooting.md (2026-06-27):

# iDryer Unit Troubleshooting

When using **iDryer Unit**, connection stability issues may occur in some cases (dropouts, MCU "disappearing", unstable operation). In most cases, this is caused not by the device itself but by external factors: vibration, electromagnetic interference, or load characteristics.

The main causes and solutions are described below.

---

## 1. USB cable vibration

!!! warning "Symptoms"
    - Intermittent connection dropouts
    - Device "disappears" from the system
    - Connection restores when touching the cable

!!! info "Cause"
    Vibrations from the printer or the dryer itself can cause micro-movements of the USB connector, leading to brief loss of contact.

!!! success "Solution"
    - Firmly secure the USB cable in the connector
    - Eliminate cable tension
    - If necessary:
        - use a cable with a tighter fit
        - secure the cable with hot glue / cable tie / holder

---

## 2. Power line interference

!!! warning "Symptoms"
    - Connection loss when heating or fan turns on
    - Random device reboots
    - Unstable operation without obvious cause

!!! info "Cause"
    AC power wires generate electromagnetic interference that induces noise on the USB cable.

!!! success "Solution"
    - Separate the USB cable and power wires as much as possible
    - Do not route them through the same cable channel
    - Avoid parallel routing over long distances
    - Install a ferrite filter (ferrite ring) on the USB cable near the controller and/or printer board

---

## 3. Fan interference

!!! warning "Symptoms"
    - Connection loss when the fan switches on/off
    - Glitches coinciding with dryer fan operation
    - Instability under PWM control

!!! info "Cause"
    A 110–230 V fan with a switching power supply can generate interference affecting signal lines.

!!! success "Solution"
    Install an **RC snubber** in parallel with the fan. Alternatively, use a ferrite filter on the USB cable.

---

## 4. USB 3.0 port — operational issues

!!! warning "Symptoms"
    - Intermittent connection dropouts during operation
    - Device "disappears" from the system without apparent reason
    - Problem disappears when switching to a different port

!!! info "Cause"
    This is a common issue with USB Full Speed (USB 2.0) devices connected to USB 3.0 ports. Modern computers use eUSB2 repeaters in USB 3.0 ports, which are not fully compatible with the USB 2.0 specification — this leads to synchronization failures and device enumeration errors. The issue is officially confirmed by STMicroelectronics: [ST FAQ](https://community.st.com/t5/stm32-mcus/faq-possible-communication-failure-between-stlink-v3-and-some/ta-p/736578).

!!! success "Solution"
    - Connect iDryer Unit **only to USB 2.0 ports** (usually black connectors)
    - If all ports are USB 3.0 — use an **active USB hub with USB 2.0 ports**

---

## 5. USB 3.0 port — flashing issues

!!! warning "Symptoms"
    - Controller not detected in bootloader mode (BOOTSEL)
    - Flashing fails or freezes
    - Device is detected but image write fails

!!! info "Cause"
    Same USB 3.0 / xHCI compatibility issue. Particularly relevant when flashing via USB Type-C ports on modern laptops — these more often use problematic eUSB2 repeaters.

!!! success "Solution"
    - When flashing, connect the controller **only to a USB 2.0 port**
    - Prefer USB Type-A ports on the rear panel of a desktop PC
    - If the problem persists — use an **active USB hub with USB 2.0 ports**

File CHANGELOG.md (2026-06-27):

### Rewritten configs to match the number of mcu's

### Translated into English

### Changed documentation structure

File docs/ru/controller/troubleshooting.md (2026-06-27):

# Проблемы со связью iDryer Unit и их решение

При использовании **iDryer Unit** в некоторых случаях могут возникать проблемы со стабильностью соединения (обрывы, «потеря» MCU, нестабильная работа).  
В большинстве случаев это связано не с самим устройством, а с внешними факторами: вибрацией, электромагнитными наводками или особенностями нагрузки.

Ниже приведены основные причины и способы их устранения.

---

## 1. Вибрация USB-кабеля

!!! warning "Симптомы"
    - Периодические обрывы соединения  
    - Устройство «пропадает» из системы  
    - Связь восстанавливается при касании кабеля  

!!! info "Причина"
    Вибрации от принтера или самой сушилки могут вызывать микроподвижки USB-разъёма, что приводит к кратковременной потере контакта.

!!! success "Решение"
    - Жёстко зафиксируйте USB-кабель в разъёме  
    - Исключите натяжение кабеля  
    - При необходимости:
        - используйте кабель с более плотной посадкой  
        - зафиксируйте кабель термоклеем / стяжкой / держателем  

---

## 2. Наводки от силовых проводов

!!! warning "Симптомы"
    - Потеря связи при включении нагрева или вентилятора  
    - Случайные перезагрузки устройства  
    - Нестабильная работа без очевидной причины  

!!! info "Причина"
    Провода питания переменного тока создают электромагнитные помехи, которые наводятся на USB-кабель.

!!! success "Решение"
    - Разнесите USB-кабель и силовые провода как можно дальше  
    - Не прокладывайте их в одном кабель-канале  
    - Избегайте параллельной прокладки на длинных участках  
    - Установите ферритовый фильтр (ферритовый цилиндр) на USB-кабель ближе к контроллеру и(или) плате принтера

---

## 3. Помехи от вентилятора

!!! warning "Симптомы"
    - Потеря связи при включении/выключении вентилятора  
    - Сбои, совпадающие с работой вентилятора сушилки  
    - Нестабильность при ШИМ-управлении  

!!! info "Причина"
    Вентилятор 110–230 В оснащён импульсным блоком питания и может создавать помехи, влияющие на сигнальные линии.

!!! success "Решение"
    Рекомендуется установить **RC-снаббер (snubber)** параллельно вентилятору. Или использовать ферритовый фильтр на USB-кабель.

---

## 4. Порт USB 3.0 — проблемы при эксплуатации

!!! warning "Симптомы"
    - Периодические обрывы соединения во время работы  
    - Устройство «пропадает» из системы без видимой причины  
    - Проблема исчезает при переключении на другой порт  

!!! info "Причина"
    Это распространённая проблема USB-устройств, работающих в режиме Full Speed (USB 2.0), при подключении к портам USB 3.0. В современных компьютерах порты USB 3.0 используют репитеры eUSB2, которые не полностью совместимы со спецификацией USB 2.0 — это приводит к сбоям синхронизации и ошибкам перечисления устройства. Проблема официально подтверждена STMicroelectronics: [FAQ на сайте ST](https://community.st.com/t5/stm32-mcus/faq-possible-communication-failure-between-stlink-v3-and-some/ta-p/736578).

!!! success "Решение"
    - Подключайте iDryer Unit **только в порты USB 2.0** (обычно чёрные разъёмы)  
    - Если все порты USB 3.0 — используйте **активный USB-хаб с портами USB 2.0**

---

## 5. Порт USB 3.0 — проблемы при прошивке

!!! warning "Симптомы"
    - Контроллер не определяется в режиме bootloader (BOOTSEL)  
    - Прошивка завершается ошибкой или зависает  
    - Устройство определяется, но запись образа не проходит  

!!! info "Причина"
    Та же проблема совместимости USB 3.0 / xHCI. Особенно актуально при прошивке через порты USB Type-C на современных ноутбуках — они чаще используют проблемные репитеры eUSB2.

!!! success "Решение"
    - При прошивке подключайте контроллер **только в порт USB 2.0**  
    - Предпочитайте порты USB Type-A на задней панели ПК  
    - Если проблема сохраняется — используйте **активный USB-хаб с портами USB 2.0**

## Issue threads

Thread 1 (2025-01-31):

Please add a language sign in the Readme

Anhsirkz, 2025-01-31:
Please add a rather big shields.io sign of supported languages to the Readme. First I actually didn't notice that there was an English `readme_en.md` file and started translating it to use for myself. 👍🏻

Anhsirkz, 2025-02-25:
Maybe adapt [this guide](https://medium.com/@samunyi90/how-to-make-custom-language-badges-for-your-profile-using-shields-io-ec69ea95dfc0) with a different svg-file or emoji 🇬🇧 at the top of the readme?
Personally I would go with the motto: "Form follows function"...

Closed 2025-04-12.

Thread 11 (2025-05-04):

old printer board as mcu?

hitman01560, 2025-05-04:
Hello! I have spare ender 3 4.2.2 boards and I would use them as controller board for your mod.

can I get some help about wiring, configuration etc please?

tried to go on Telegram but only Russian is spoken so I can do nothing...

thanks!

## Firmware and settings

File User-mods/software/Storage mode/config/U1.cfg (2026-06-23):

[gcode_macro _SETTINGS_U1]
variable_delta_high          : 15   #degrees, celsius
variable_hyst_humidity       : 2    #humidity histeresis for storage mode, degrees
variable_servo_open_angle    : 30   #degrees
variable_servo_closed_angle  : 85   #degrees
variable_servo_open_time     : 10   #second
variable_servo_closed_time   : 600  #second
variable_max_bright          : 0.5  #maximum brightness of indicators range from 0 to 1
variable_min_bright          : 0.02 #minimum brightness of indicators range from 0 to 1
### Do not touch the variables below!!! ###
variable_temp: 55
variable_humidity: 10
variable_time: 180
variable_off_timer: 0
variable_dry_mode: 0
variable_storage_mode: 0
variable_storage_heat: 0
variable_servo_n: 0
variable_servo_steps: 55
variable_servo_step_duration: 0.2
variable_kp: 7.2
variable_ki: 0.45
variable_kd: 28.8
variable_int: 0
variable_perror: 0
gcode:

[heater_generic iDryer_U1_Heater]
heater_pin: H_U1
sensor_type: NTC 100K MGB18-104F39050L32
sensor_pin: T_U1
min_temp: 0
max_temp: 110
control: pid
pid_Kp=47.184
pid_Ki=3.114
pid_Kd=178.711

[verify_heater iDryer_U1_Heater]
max_error: 240
check_gain_time: 120
heating_gain: 1

[heater_fan Fan_U1]
pin: FAN_U1
heater: iDryer_U1_Heater
heater_temp: 55

[temperature_sensor iDryer_U1_Air]
sensor_type: SHT3X
i2c_bus: i2c0f
i2c_address: 68

[servo srv_U1]
pin: SRV_U1
minimum_pulse_width: 0.00054
maximum_pulse_width: 0.00245

[neopixel sprd]
pin: NEOPIXEL0
chain_count: 4
initial_RED: 0
initial_GREEN: 0
initial_BLUE: 0

[idle_timeout]
gcode:

[save_variables]
filename: ~/printer_data/config/iDryer_mcu/variables_u1.cfg

[display_template led_heater]
text:
    {% set unit = printer["gcode_macro _SETTINGS_U1"] %}
    {% set heater = printer["heater_generic iDryer_U1_Heater"].power|float %}
    
    {% if heater %}
        {% set r = unit.max_bright %}
        {% set g = 0 %}
        {% set b = unit.max_bright %}
    {% else %}
        {% set r = unit.min_bright %}
        {% set g = unit.min_bright %}
        {% set b = unit.min_bright %}
    {% endif %}
    {r}, {g}, {b}

[display_template led_fan]
text:
    {% set unit = printer["gcode_macro _SETTINGS_U1"] %}
    {% set fan = printer["heater_fan Fan_U1"].speed|float %}
    
    {% if fan %}
        {% set r = 0 %}
        {% set g = unit.max_bright %}
        {% set b = unit.max_bright %}
    {% else %}
        {% set r = unit.min_bright %}
        {% set g = unit.min_bright %}
        {% set b = unit.min_bright %}
    {% endif %}
    {r}, {g}, {b}
    
[display_template led_humidity]
text:
    {% set unit = printer["gcode_macro _SETTINGS_U1"] %}
    {% set humidity = printer["sht3x iDryer_U1_Air"].humidity|float %}

    {% if unit.storage_mode %}
        {% set r = 0 %}
        {% set g = unit.max_bright %}
        {% set b = 0 %}
    {% else %}
        {% if humidity < 5 %}
            {% set r = unit.max_bright %}
            {% set g = unit.max_bright * 0.5 %}
            {% set b = 0 %}
        {% elif humidity >= 5 and humidity <= 30 %}
            {% set r = (unit.max_bright - (humidity - 5) * unit.max_bright / 25)|round(3) %}
            {% set g = (unit.max_bright * 0.5 - (humidity - 5) * unit.max_bright * 0.5 / 25)|round(3) %}
            {% set b = ((humidity - 5) * unit.max_bright / 25)|round(3) %}
        {% else %}
            {% set r = 0 %}
            {% set g = 0 %}
            {% set b = unit.max_bright %}
        {% endif %}
    {% endif %}
    {r}, {g}, {b}

[display_template led_temp]
text:
    {% set unit = printer["gcode_macro _SETTINGS_U1"] %}
    {% set temp = printer["temperature_sensor iDryer_U1_Air"].temperature|float %}
    
    {% if temp < 25 %}
        {% set r = 0 %}
        {% set g = 0 %}
        {% set b = unit.max_bright %}
    {% elif temp >= 25 and temp <= 55 %}
        {% set r = ((temp - 25) * unit.max_bright / 30)|round(3) %}
        {% set g = 0 %}
        {% set b = (unit.max_bright - (temp - 25) * unit.max_bright / 30)|round(3) %}
    {% else %}
        {% set r = unit.max_bright %}
        {% set g = 0 %}
        {% set b = 0 %}
    {% endif %}
    {r}, {g}, {b}

[delayed_gcode _AFTER_BOOT]
initial_duration: 1
gcode:
    SET_LED_TEMPLATE LED=sprd INDEX=1 TEMPLATE=led_heater
    SET_LED_TEMPLATE LED=sprd INDEX=2 TEMPLATE=led_fan
    SET_LED_TEMPLATE LED=sprd INDEX=3 TEMPLATE=led_humidity
    SET_LED_TEMPLATE LED=sprd INDEX=4 TEMPLATE=led_temp
    _SERVO_CLOSE_U1

[gcode_macro PLA_U1]
gcode:
    DRY_U1 TEMPERATURE=55 HUMIDITY=10 TIME=180

[gcode_macro TPU_U1]
gcode:
    DRY_U1 TEMPERATURE=60 HUMIDITY=10 TIME=300

[gcode_macro PETG_U1]
gcode:
    DRY_U1 TEMPERATURE=65 HUMIDITY=10 TIME=240

[gcode_macro ABS_U1]
gcode:
    DRY_U1 TEMPERATURE=80 HUMIDITY=10 TIME=240

[gcode_macro PA_U1]
gcode:
    DRY_U1 TEMPERATURE=90 HUMIDITY=10 TIME=240

[gcode_macro DRY_U1]
gcode:
    {% set unit = printer["gcode_macro _SETTINGS_U1"] %}
    {% set svv = printer.save_variables.variables %}
    
    {% set set_temp = params.TEMPERATURE|default(55)|int %} 
    {% set set_humidity = params.HUMIDITY|default(10)|int %} 
    {% set set_time = params.TIME|default(180)|int %}

    _STOP_MACROS_U1

    SET_GCODE_VARIABLE MACRO=_SETTINGS_U1 VARIABLE=temp VALUE={set_temp}
    SET_GCODE_VARIABLE MACRO=_SETTINGS_U1 VARIABLE=humidity VALUE={set_humidity}
    SET_GCODE_VARIABLE MACRO=_SETTINGS_U1 VARIABLE=time VALUE={set_time}
    SET_GCODE_VARIABLE MACRO=_SETTINGS_U1 VARIABLE=off_timer VALUE=0
    SET_GCODE_VARIABLE MACRO=_SETTINGS_U1 VARIABLE=servo_n VALUE=0
    SET_GCODE_VARIABLE MACRO=_SETTINGS_U1 VARIABLE=dry_mode VALUE=1
    SET_GCODE_VARIABLE MACRO=_SETTINGS_U1 VARIABLE=storage_mode VALUE=0
    
    UPDATE_DELAYED_GCODE ID=_UPDATE_U1 DURATION=1
    
    {% set pref = "tgnotify" if svv.telegram else "" %}
    RESPOND PREFIX={pref} MSG="iDryer_U1 Temp: {set_temp}C Humidity: {set_humidity}% Timer: {set_time} min Current humidity: {printer["sht3x iDryer_U1_Air"].humidity}%"

[gcode_macro STORAGE_U1]
gcode:
    {% set unit = printer["gcode_macro _SETTINGS_U1"] %}
    {% set svv = printer.save_variables.variables %}

    {% if params.TEMPERATURE is defined %}
        {% set set_temp = params.TEMPERATURE|default(55)|int %}
        SET_GCODE_VARIABLE MACRO=_SETTINGS_U1 VARIABLE=temp VALUE={set_temp}
    {% else %}
        {% set set_temp = unit.temp %}
    {% endif %}
    {% if params.HUMIDITY is defined %}
        {% set set_humidity = params.HUMIDITY|default(10)|int %}
        SET_GCODE_VARIABLE MACRO=_SETTINGS_U1 VARIABLE=humidity VALUE={set_humidity}
    {% else %}
        {% set set_humidity = unit.humidity %}
    {% endif %}

    _STOP_MACROS_U1

    SET_GCODE_VARIABLE MACRO=_SETTINGS_U1 VARIABLE=storage_mode VALUE=1
    SET_GCODE_VARIABLE MACRO=_SETTINGS_U1 VARIABLE=dry_mode VALUE=0
    SET_GCODE_VARIABLE MACRO=_SETTINGS_U1 VARIABLE=storage_heat VALUE=1

    UPDATE_DELAYED_GCODE ID=_STORAGE_U1 DURATION=1
    
    {% set pref = "tgnotify" if svv.telegram else "" %}
    RESPOND PREFIX={pref} MSG="STORAGE_U1 Temp: {set_temp}C Humidity: {set_humidity}% Current humidity: {printer["sht3x iDryer_U1_Air"].humidity}%"

[gcode_macro OFF_U1]
gcode:
    {% set svv = printer.save_variables.variables %}

    _STOP_MACROS_U1
    
    SET_GCODE_VARIABLE MACRO=_SETTINGS_U1 VARIABLE=storage_mode VALUE=0
    SET_GCODE_VARIABLE MACRO=_SETTINGS_U1 VARIABLE=dry_mode VALUE=0
    SET_GCODE_VARIABLE MACRO=_SETTINGS_U1 VARIABLE=int VALUE=0

    {% set pref = "tgnotify" if svv.telegram else "" %}
    RESPOND PREFIX={pref} MSG="iDryer_U1 is OFF, current humidity: {printer["sht3x iDryer_U1_Air"].humidity}%"
    
[gcode_macro STATUS_U1]
gcode:
    {% set unit = printer["gcode_macro _SETTINGS_U1"] %}
    {% set svv = printer.save_variables.variables %}
    {% set heater = "ON" if printer["heater_generic iDryer_U1_Heater"].power else "OFF" %}
    {% set humidity = printer["sht3x iDryer_U1_Air"].humidity %}
    {% set temp = printer["temperature_sensor iDryer_U1_Air"].temperature|round(1) %}
    {% set pref = "tgnotify" if svv.telegram else "" %}
    {% set mode = "Drying" if unit.dry_mode else "Storage" if unit.storage_mode else "OFF" %}
    RESPOND PREFIX={pref} MSG="iDryer_U1 mode: {mode} Temp: {temp}C Humidity: {humidity}% Heater: {heater} Storage after timer: {svv.storage_after_timer}"

[gcode_macro STORAGE_AFTER_TIMER_U1]
gcode:
    {% set svv = printer.save_variables.variables %}
    {% if svv.storage_after_timer %}
        SAVE_VARIABLE VARIABLE=storage_after_timer VALUE=0
        {% set pref = "tgnotify" if svv.telegram else "" %}
        RESPOND PREFIX={pref} MSG="iDryer_U1 will turn OFF when the timer ends"
    {% else %}
        SAVE_VARIABLE VARIABLE=storage_after_timer VALUE=1
        {% set pref = "tgnotify" if svv.telegram else "" %}
        RESPOND PREFIX={pref} MSG="iDryer_U1 storage mode will be enabled after the timer expires"
    {% endif %}
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

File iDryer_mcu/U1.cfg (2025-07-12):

#PID_CALIBRATE HEATER=iDryer_U1_Heater TARGET=100

#==================================================
#=====================CONFIG=======================
#==================================================
[heater_generic iDryer_U1_Heater]
heater_pin: H_U1
max_power: 1
sensor_type: NTC 100K MGB18-104F39050L32 #Generic 3950
sensor_pin: gpio26
control: pid
pwm_cycle_time: 0.3
min_temp: 0
max_temp: 125
pid_Kp=29.625
pid_Ki=0.945
pid_Kd=232.186


[verify_heater iDryer_U1_Heater]
max_error: 240
check_gain_time: 120
heating_gain: 1


[heater_fan Fan_U1]
fan_speed: 1
pin: FAN_U1
heater: iDryer_U1_Heater
heater_temp: 55


#==================================================
#=======================SHT========================
#==================================================
[temperature_sensor iDryer_U1_Air]
sensor_type: SHT3X
# if your iDryer is used as a second MCU uncomment:
# i2c_mcu: iDryer
i2c_bus: i2c0f
i2c_address: 68 # 68 or 69 https://learn.adafruit.com/adafruit-sht31-d-temperature-and-humidity-sensor-breakout/pinouts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
# i2c_software_sda_pin: gpio20 #second HW version - green PCB | i2c_software_sda_pin: gpio18 #first HW version - red PCB
# i2c_software_scl_pin: gpio21 #second HW version - green PCB | # i2c_software_scl_pin: gpio19 #first HW version - red PCB

[gcode_macro HUMIDITY_QUERY_IDRYER_U1]
gcode:
    {action_respond_info("U1 Humidity  %.2f%%" %(printer["sht3x iDryer_U1_Air"].humidity))}


[gcode_macro QUERY_IDRYER_U1]
# [gcode_macro SHOW]
gcode:
    {action_respond_info("U1 temperature: %.2f C, Humidity: %.2f%%" % (
        printer["sht3x iDryer_U1_Air"].temperature,
        printer["sht3x iDryer_U1_Air"].humidity))}

#==================================================
#=====================BME280=======================
#==================================================
# [temperature_sensor iDryer_U1_Air]
# sensor_type: BME280
# i2c_mcu: iDryer
# i2c_address: 118 
# i2c_bus: i2c0f


#==================================================
#=====================SERVO========================
# https://www.klipper3d.org/Config_Reference.html?h=temper#servo
#==================================================

[servo srv_U1]
pin: SRV_U1
maximum_servo_angle: 180
minimum_pulse_width: 0.00055 #0.00055
maximum_pulse_width: 0.002


[gcode_macro servo_U1]
gcode:
    {% set angle = params.ANGLE|default(90)|int %} 
    SET_SERVO SERVO=srv_U1 ANGLE={angle}
    

[delayed_gcode _TOGGLE_SERVO_U1]
gcode:
    {% set unit_data = printer['gcode_macro DRY_U1'] %}
    {% set servo_angle = unit_data.servo_angle %}
    
    HUMIDITY_QUERY_IDRYER_U1
    {% if servo_angle == printer['gcode_macro DRY_U1'].servo_open_angle %}
        SET_SERVO SERVO=srv_U1 ANGLE={printer['gcode_macro DRY_U1'].servo_closed_angle}
        { action_respond_info("----------SERVO CLOSE ---------- servo_angle  %s" %(servo_angle))}
        
        SET_GCODE_VARIABLE MACRO=DRY_U1 VARIABLE=servo_angle VALUE={printer['gcode_macro DRY_U1'].servo_closed_angle}
        UPDATE_DELAYED_GCODE ID=_TOGGLE_SERVO_U1 DURATION={printer['gcode_macro DRY_U1'].servo_closed_time}
    {% elif servo_angle == printer['gcode_macro DRY_U1'].servo_closed_angle %}
        SET_SERVO SERVO=srv_U1 ANGLE={printer['gcode_macro DRY_U1'].servo_open_angle}
        { action_respond_info("----------SERVO OPEN ---------- servo_angle  %s" %(servo_angle))}
        
        SET_GCODE_VARIABLE MACRO=DRY_U1 VARIABLE=servo_angle VALUE={printer['gcode_macro DRY_U1'].servo_open_angle}
        UPDATE_DELAYED_GCODE ID=_TOGGLE_SERVO_U1 DURATION={printer['gcode_macro DRY_U1'].servo_open_time}
    {% endif %}


#==================================================
#=======================NEOPIXEL===================
# https://www.klipper3d.org/Config_Reference.html?h=temper#neopixel
#==================================================
[neopixel sprd]
pin: NEOPIXEL0
chain_count: 4
color_order: GRB
initial_RED: 0.1
initial_GREEN: 0.0
initial_BLUE: 0.0


[gcode_macro SPRD]
gcode:
    {% set R = params.R|default(1.0)|float %} 
    {% set G = params.G|default(0.0)|float %} 
    {% set B = params.B|default(1.0)|float %} 
    {% for i in range(1,5)%}
      SET_LED LED=sprd RED={R} GREEN={G} BLUE={B} WHITE=0 INDEX={i} TRANSMIT=1 SYNC=0
        G4 P1000  
    {% endfor %}


[delayed_gcode LED_SERVICE]
gcode:
    {% set cur_heater_state =   printer['heater_generic iDryer_U1_Heater'].power|float %} 
    {% set cur_fan_state =      printer['heater_fan Fan_U1'].speed|float%} 
    {% set cur_unit_humidity =  printer["sht3x iDryer_U1_Air"].humidity|float%}
    {% set cur_unit_temp =      printer['temperature_sensor iDryer_U1_Air'].temperature|float%}

    {% if cur_unit_humidity < 20 %}
        {% set humidity_r = 1.0 - (cur_unit_humidity / 20.0) %}
        {% set humidity_g = 1.0 - (cur_unit_humidity / 20.0) %}
        {% set humidity_b = cur_unit_humidity / 20.0 %}
    {% else %}
        {% set humidity_r = 0.0 %}
        {% set humidity_g = 0.0 %}
        {% set humidity_b = (cur_unit_humidity - 20.0) / 80.0 %}
    {% endif %}
    
    {% if cur_fan_state != 1.0 %}
        {% set cur_fan_state = 0.01 %}
    {% endif %}

    {% if cur_unit_temp < 50 %}
        {% set red_intensity = 0.01 %}
    {% else %}
        {% set red_intensity = ((cur_unit_temp - 30) / 70) ** 0.5 %}
        {% set red_intensity = red_intensity if red_intensity <= 1.0 else 1.0 %}
        {% set red_intensity = red_intensity if red_intensity >= 0.01 else 0.01 %}
    {% endif %}

    SET_LED LED=sprd RED={cur_heater_state}     GREEN={0.01}                BLUE={0.01}                 WHITE=0 INDEX={1}   # heater
    SET_LED LED=sprd RED={0.01}                 GREEN={cur_fan_state}       BLUE={0.01}                 WHITE=0 INDEX={2}    # fan
    SET_LED LED=sprd RED={humidity_r}           GREEN={humidity_g}          BLUE={humidity_b}           WHITE=0 INDEX={3}   # humidity
    SET_LED LED=sprd RED={red_intensity}        GREEN={0.01}                BLUE={0.01}                 WHITE=0 INDEX={4} TRANSMIT=1 SYNC=0 # temperature

    UPDATE_DELAYED_GCODE ID=LED_SERVICE DURATION=5


[gcode_macro LED_BLINK]
gcode:
    {% set colors = [
        {'R': 1.0, 'G': 0.0, 'B': 0.0},  
        {'R': 0.0, 'G': 1.0, 'B': 0.0},  
        {'R': 0.0, 'G': 0.0, 'B': 1.0}, 
        {'R': 1.0, 'G': 1.0, 'B': 0.0}   
    ] %}
    
    {% for i in range(blink_count) %}
        {% for j in range(4) %}
            {% set color = colors[j] %}
            SET_LED LED=sprd RED={color.R} GREEN={color.G} BLUE={color.B} WHITE=0 INDEX={j+1} TRANSMIT=1 SYNC=0
            G4 P100; 
            SET_LED LED=sprd RED=0 GREEN=0 BLUE=0 WHITE=0 INDEX={j+1} TRANSMIT=1 SYNC=0
            G4 P100 
        {% endfor %}
    {% endfor %}


[gcode_macro LED_RAINBOW]
gcode:
    {% set num_leds = 4 %} 
    {% set steps = 500 %} 
    {% set delay = 50 %}  

    {% for step in range(steps) %}
        {% for i in range(num_leds) %}
            {% set position = (step * 360 / steps + i * (360 / num_leds)) % 360 %}

            {% if position < 120 %}
                {% set red = 1.0 - position / 120.0 %}
                {% set green = position / 120.0 %}
                {% set blue = 0.0 %}
            {% elif position < 240 %}
                {% set red = 0.0 %}
                {% set green = 1.0 - (position - 120) / 120.0 %}
                {% set blue = (position - 120) / 120.0 %}
            {% else %}
                {% set red = (position - 240) / 120.0 %}
                {% set green = 0.0 %}
                {% set blue = 1.0 - (position - 240) / 120.0 %}
            {% endif %}

            SET_LED LED=sprd RED={red|float} GREEN={green|float} BLUE={blue|float} WHITE=0 INDEX={i+1} TRANSMIT=1 SYNC=0
        {% endfor %}
        G4 P{delay} ;
    {% endfor %}


#========================================================
#=====================iDryer macros======================
#========================================================
[gcode_macro OFF_U1]
gcode:
    UPDATE_DELAYED_GCODE ID=_UPDATE_U1 DURATION=0
    UPDATE_DELAYED_GCODE ID=_TOGGLE_SERVO_U1 DURATION=0
    SET_HEATER_TEMPERATURE HEATER=iDryer_U1_Heater TARGET=0

[delayed_gcode _OFF_U1]
gcode:
    OFF_U1


[gcode_macro PLA_U1]
variable_unit_temp: 55
variable_unit_duration: 180
gcode:
    DRY_U1 UNIT_TEMPERATURE={unit_temp} HUMIDITY=10 TIME={unit_duration}


[gcode_macro PETG_U1]
variable_unit_temp: 65
variable_unit_duration: 240
gcode:
    DRY_U1 UNIT_TEMPERATURE={unit_temp} HUMIDITY=10 TIME={unit_duration}


[gcode_macro TPU_U1]
variable_unit_temp: 60
variable_unit_duration: 300
gcode:
    DRY_U1 UNIT_TEMPERATURE={unit_temp} HUMIDITY=10 TIME={unit_duration}


[gcode_macro ABS_U1]
variable_unit_temp: 80
variable_unit_duration: 240
gcode:
    DRY_U1 UNIT_TEMPERATURE={unit_temp} HUMIDITY=10 TIME={unit_duration}


[gcode_macro PA_U1]
variable_unit_temp: 90
variable_unit_duration: 240
gcode:
    DRY_U1 UNIT_TEMPERATURE={unit_temp} HUMIDITY=10 TIME={unit_duration}
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

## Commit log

2024-11-05 cad+img add
    [Nameplate UNIT.3mf, Set 1.3mf, Set 2.3mf]
2024-11-07 set 1.3mf upd
    [Set 1.3mf]
2024-11-15 redme upd
    [NameplateUNIT.3mf, Set 2.3mf, Set1.3mf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]
2024-11-21 CAD upd
    [NameplateUNIT.3mf, Set1.3mf, Set2.3mf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]
2025-01-24 stl update, user mods and readme add
    [Nameplate UNIT.3mf, NameplateUNIT.3mf, Set 1.3mf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]
2025-01-24 Updated files: added new files, removed unused files
    [UNIT Back Cover 2.stl, UNIT Back Cover.stl, UNIT Cover.stl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]
2025-01-24 UNIT floor
    [UNIT Floor.stl]
2025-01-25 floor upd
    [UNIT Floor Sensor Retainer.stl, UNIT Floor.stl]
2025-01-25 UNIT Top Cover screw mounting upd
    [UNIT Top Cover screw mounting.stl]
2025-01-28 readme_en upd
    [U1.cfg, UNIT Top Cover screw mounting.stl, iDryer.cfg]
2025-01-29 mods add
    [U1.cfg, UNIT Extreme heater spacer Left.stl, UNIT Extreme heater spacer Right.stl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]
2025-02-05 _OFF_U_n add
    [U1.cfg, U2.cfg, U3.cfg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]
2025-02-05 delayed_gcode _OFF_U_n upd
    [U1.cfg, U2.cfg, U3.cfg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]
2025-02-20 duo add
    [UNIT MCU duo Back Cover.stl, UNIT duo Top Cover screw mounting.stl, UNIT duo silica tray.stl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]
2025-02-26 bme280 add
    [U1.cfg]
2025-02-28 Added CoolMod
    [EBB42_SSR-40_DA_Electronic_cover.stl, EBB42_SSR40_DA.stl]
2025-02-28 Added ebb42mod
    [EBB42_SSR-40_DA_Electronic_cover.stl]
2025-03-01 Add UART mod
    [Крышка Электроники (U2+U3).stl, Крышка Электроники (U2+U3).stp]
2025-03-21 Mod add
    [Clean Cartrige v2.3mf, Clean Cartrige v2.step, Output Filament v9.3.3mf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]
2025-04-07 i2c address has been changed
    [U1.cfg, U2.cfg, U3.cfg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]
2025-06-07 Local changes in iDryer-Unit
    [Base-Mag10x2.7.step, Base-Mag10x2.7.stl, Clean Cartrige v2.3mf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]
2025-06-10 splitting mcu and second_mcu configs into folders
    [U1.cfg, U2.cfg, U3.cfg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]
2025-06-10 deletion of unused files
    [gpio_test.cfg, mainsail.cfg, search_vars.cfg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]
2025-06-10 sh add
    [U1.cfg, U4.cfg, iDryer.cfg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]
2025-08-17 Update backcover models and readme
    [EE_BackCover (Old_PCB).STEP, EE_BackCover.STEP]
2026-04-29 ADD: opi zero 2w mod files
    [EE_BackCover (Old_PCB).STEP, EE_BackCover.STEP, EE_Side_L (Old_PCB).STEP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]
2026-06-30 Fix typos in display panel references in CAD documentation
2026-07-13 Add BOM page for iDryer Unit with translations and images
    [bom.csv]
2026-07-14 Add material consumption note to CAD pages across all languages
    [bom.csv]
